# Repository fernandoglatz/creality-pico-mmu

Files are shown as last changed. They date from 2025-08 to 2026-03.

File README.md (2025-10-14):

# Creality Pico MMU

A firmware and tooling stack for a custom **8-line Multi-Material Unit (MMU)** for the **Creality Ender 3 V3 KE** 3D printer. The project provides:

* A **C++ firmware** for ATmega328P (Arduino Pro Mini/Nano) that controls the MMU hardware via serial communication.
* A **Python daemon** (`mmu_daemon.py`) that manages serial communication, provides automatic reconnection, and integrates with Klipper via socket interface.
* A **Python command-line interface** (`mmu_cmd.py`) to send commands to the MMU daemon.
* **Klipper configuration** (`pico-mmu.cfg`) with macros for seamless integration with Klipper firmware.
* Hardware designs for filament cutter and filament hub components.

## Features

✨ **8-Line Multi-Material System**
- Supports up to 8 different filament colors/materials simultaneously
- Individual filament presence sensors for each line
- Real-time filament state monitoring

🎯 **Automatic Filament Management**
- Servo-driven filament selector with precise positioning
- Automatic filament cutting between material changes
- Smart extrude/retract with acceleration control
- Stuck filament detection and error handling

🔌 **Seamless Klipper Integration**
- Native G-code macros (T0-T7 for tool changes)
- Daemon-based architecture with automatic reconnection
- HTTP API integration with Klipper
- State persistence across restarts

💡 **Visual & Audio Feedback**
- 16 RGB LEDs (WS2812B) showing filament status
- Color-coded status indicators per filament
- Musical notifications for events (startup, errors, success)
- Action button for manual control

🛠️ **Hardware Design Included**
- Custom filament cutter with dual 5015 fan cooling
- 9-line filament hub with integrated runout sensor
- Protoboard wiring diagram for easy assembly
- 3D printable STL files available on Printables

⚙️ **Highly Configurable**
- Adjustable servo positions, speeds, and distances
- Configurable acceleration curves
- Per-setup calibration via Klipper macros
- Runtime parameter synchronization

## System Requirements

### Hardware
- Creality Ender 3 V3 KE (or compatible 3D printer)
- ATmega328P microcontroller (Arduino Pro Mini 16MHz or Arduino Nano)
- MCP23017 I2C I/O expander
- 2x Servo motors (selector + cutter)
- Stepper motor with driver for filament feeding
- WS2812B NeoPixel LED strip (16 LEDs)
- 8x Filament sensors + 1x Hub sensor
- Piezo buzzer
- Push button
- Various electronics components (see Hardware section)

### Software
- Klipper firmware on printer
- Python 3.x
- PlatformIO (for firmware compilation)
- pyserial Python library

---

## Table of Contents

- [Creality Pico MMU](#creality-pico-mmu)
  - [Features](#features)
  - [System Requirements](#system-requirements)
  - [Table of Contents](#table-of-contents)
  - [Hardware](#hardware)
  - [Filament Cutter](#filament-cutter)
  - [Filament Hub](#filament-hub)
  - [Software Architecture](#software-architecture)
  - [Getting Started](#getting-started)
  - [Building the Firmware](#building-the-firmware)
  - [Running the Daemon](#running-the-daemon)
  - [Command Line Tool](#command-line-tool)
  - [Klipper Integration](#klipper-integration)
  - [Troubleshooting](#troubleshooting)
  - [Development](#development)
  - [Contributing](#contributing)
  - [License](#license)

---

## Hardware

The firmware targets an **ATmega328P** microcontroller (Arduino Pro Mini or Arduino Nano) that controls an 8-line MMU system with integrated sensors, servos, and LED feedback. 

### Core Components

- **Microcontroller**: ATmega328P (Arduino Pro Mini 16MHz or Arduino Nano)
- **I/O Expander**: MCP23017 (I2C) - provides 16 additional GPIO pins for sensors and control
- **LED System**: WS2812B NeoPixel strip (16 LEDs arranged as 2 bars of 8 LEDs each)
- **Servos**: 
  - MMU selector servo (positions filament selector wheel)
  - Filament cutter servo (operates cutting mechanism)
- **Stepper Motor**: Controls filament feeding/retracting with configurable acceleration/deceleration
- **Audio Feedback**: Piezo buzzer for status notifications
- **Sensors**:
  - 8x filament presence sensors (one per filament line)
  - 1x filament hub sensor (detects filament movement)
  - 1x action button (manual control)

### Pin Configuration

#### Direct ATmega328P Pins
| Pin | Function | Description |
|-----|---|---|
| D2 | Filament Hub Sensor | Interrupt-driven sensor for filament movement detection |
| D3 | Cutter Servo PWM | Controls filament cutting servo |
| D5 | NeoPixel Data | WS2812B LED strip data line |
| D6 | Buzzer | Piezo buzzer for audio feedback |
| D7 | MMU Direction | Stepper motor direction control |
| D8 | MMU Step | Stepper motor step signal |
| D9 | MMU Enable | Stepper motor enable/disable |
| D10 | MMU Servo PWM | Controls MMU selector servo |
| SDA/SCL | I2C Bus | Communication with MCP23017 |

#### MCP23017 I/O Expander Pins
| Pin | Function | Description |
|-----|---|---|
| 0 | Action Button | Manual control button (INPUT_PULLUP) |
| 1 | Creality Filament Sensor | Output signal to printer's filament runout sensor |
| 8-15 | Filament Sensors 1-8 | Individual filament presence detection (INPUT_PULLUP) |

### Hardware Features

- **Stepper Motor Control**: Microstepping (64 microsteps), configurable RPM (50-500), acceleration/deceleration curves
- **LED Status Indicators**: Per-filament status (idle, active, loaded, error states)
- **Audio Notifications**: Startup, error, filament inserted/removed, success melodies
- **Sensor Monitoring**: Real-time filament presence and movement detection
- **Servo Control**: Precise positioning for filament selection and cutting

The `pcb/` directory contains a protoboard diagram (`protoboard-diagram.fzz`) for wiring the components.

## Filament Cutter

The **Filament Cutter** is a custom toolhead modification designed specifically for use with the 8-line Pico MMU on the **Creality Ender 3 V3 KE**. This component enables automatic filament cutting between material changes, eliminating the need for manual intervention.

The design is based on the FatBurner cooling system and integrates a servo-driven blade mechanism that cuts the filament between the extruder motor and the hotend.

**Model files:** [Printables - Filament Cutter](https://www.printables.com/model/1433552-filament-cutter-creality-ender-3-v3-ke)

### Features

- Servo-driven cutting mechanism using TD-8120MG (20Kg) or MG995 (10Kg) servo
- Integrated dual 5015 fan cooling system (FatBurner-based)
- 4020 hotend fan adapter
- Compact design that fits between the extruder motor and hotend
- Uses standard box cutter blade for reliable cutting

### Required Parts

- **8x** Brass insert nut M3 (4mm OD x 4mm length)
- **4x** Superb screws (for the fan adapter)
- **4x** M3 flat head Allen screws (20mm)
- **2x** M3 flat head Allen screws (8mm)
- **1x** M3 flat head Allen screw (6mm)
- **4x** M3 Allen screws (8mm)
- **2x** M3 Allen screws (25mm)
- **2x** Fan 5015 (24V)
- **1x** Fan 4020 (24V)
- **3x** JST SH1 mini 1.25mm connector
- **6x** Heat shrink tubes
- **1x** Servo TD-8120MG (20Kg) or MG995 (10Kg)
- **1x** PTFE tube (1m, Creality 2mm ID)
- **1x** Box cutter blade

### Print Settings

- **Infill:** 100%
- **Support:** Yes
- **Support Type:** Snug and Tree Organic (for the FatBurner frame)
- **Raft Layers:** 10 (only for the FatBurner frame)

**Recommendations:**
- Print parts close to the hotend in **ABS** to avoid PLA deformation
- Use the **TD-8120MG 20Kg servo** for better robustness
- Verify your MMU board supports the servo current requirements
- Check camera mount clearance to avoid collisions

### Assembly Instructions

1. **Print all parts** using the provided 3MF file in `models/filament-cutter/`
2. **Insert brass insert nuts** into all designated holes
3. **Modify fan connectors:**
   - Replace 5015 and 4020 fan connectors with JST SH1 mini
   - May need to invert GND/24V pins in the connector
4. **Assemble cooling system:**
   - Attach 5015 fans to the FatBurner frame
   - Attach 40mm fan adapter to the hotend
   - Attach 4020 fan to the adapter
5. **Prepare hotend:**
   - Disassemble the toolhead (detach radiator from rear panel)
   - Cut PTFE tube, leaving only 1mm protruding from hotend radiator
   - Make an internal cone-shaped cut in the PTFE to facilitate filament entry
6. **Install cutting mechanism:**
   - Attach cutting base to hotend radiator using 25mm screws
   - Attach extruder motor
   - Insert box cutter blade into blade support using pliers (use cyanoacrylate glue to secure)
7. **Test cutting:**
   - Insert filament for testing
   - Manually push blade support into cutting base to verify cutting action
8. **Final assembly:**
   - Connect fans to extruder plate
   - Attach FatBurner frame with 6mm screw
   - Position servo holder with 8mm screws
   - Insert gear into servo (requires considerable force)
9. **Servo setup:**
   - Connect servo to power and set to initial position (0°)
   - Insert blade support, lightly touch filament, then back off 1mm
   - Insert servo into holder (mark blade support position for future maintenance)
   - Tighten all servo screws
   - Test cutting angle electronically (typically ~90°, always return to 0° between tests)
   - Apply petroleum jelly to moving parts

### Design Notes

This filament cutter is a remix that combines elements from several existing designs:

- Based on [FatBurner cooling system](https://www.printables.com/model/887597-fatburner-ender-3-v3-ke-dual-5015-fan-cooling-syst)
- Adapted cutting mechanism from [Ender 3 V3 SE filament cutter](https://www.printables.com/model/1277295-filament-cutter-for-ender-3-v3-se-servo-motor-edit)
- Uses [40mm fan adapter](https://www.printables.com/model/718283-ender-3-v3-se-25-40mm-fan-bracket-low-profile)

**Key modifications:**
- Custom cutout in FatBurner frame to accommodate filament cutter
- Shortened right-side duct for improved airflow
- Relocated mounting holes and reinforced structure on cutting base

## Filament Hub

The **Filament Hub** is a 9-line filament distribution system designed for the custom 8-line Pico MMU on the **Creality Ender 3 V3 KE**. It manages multiple filament feeds and includes an integrated filament runout sensor to detect when filament runs out during printing.

The hub uses ECAS04 push-to-connect fittings for quick and secure PTFE tube connections, and features a KW11-3Z micro switch for runout detection.

**Model files:** [Printables - Filament Hub 9 Lines](https://www.printables.com/model/1432682-filament-hub-9-lines-creality-ender-3-v3-ke)

### Features

- 9-line capacity (supports 8-line MMU plus one spare)
- Integrated filament runout sensor with micro switch
- ECAS04 quick-connect fittings for all filament lines
- Compact design suitable for mounting on printer frame
- Compatible with standard 1.75mm filament

### Required Parts

- **2x** M3 Allen screws (8mm)
- **2x** M3 Allen screws (10mm)
- **9x** ECAS04 connector (push-to-connect PTFE fittings)
- **1x** KW11-3Z micro switch (filament runout sensor)
- **1x** Zip tie (for cable management)

### Print Settings

- **Infill:** 100%
- **Support:** Yes
- **Support Type:** Tree Organic
- **Raft Layers:** 10

**Important Notes:**
- Do **NOT** add support on top of the hub - supports must only be on the bottom/sides
- Adding supports on top will make them impossible to remove and may damage the hub
- All models are oriented correctly for printing in the 3MF file

### Assembly and Maintenance

1. **Print the hub** using the provided 3MF file in `models/filament-hub/`
2. **Install ECAS04 connectors:**
   - Insert connectors into all 9 ports
   - Use cyanoacrylate glue to secure them permanently
3. **Install micro switch:**
   - Mount the KW11-3Z micro switch in the designated position
   - Secure with appropriate screws
4. **Mount the hub:**
   - Use M3 screws (8mm and 10mm) to mount hub to printer frame
   - Use zip tie for cable management
5. **Lubrication:**
   - Apply petroleum jelly to the inside of the hub
   - Apply petroleum jelly to the switch end cap
   - This ensures smooth filament movement and prevents binding
6. **Calibration:**
   - Test with different filament types
   - Adjust micro switch end-of-travel angle if needed for reliable detection
   - Fine-tune based on filament diameter variations

### Design Notes

This hub is a remix based on the [Filament Runout Sensor Enclosure](https://www.printables.com/model/11416-filament-runout-sensor-enclosure) by stevehlau, customized specifically for the Creality Ender 3 V3 KE and integrated with the 8-line Pico MMU system.

**Key features of the remix:**
- Expanded to 9 lines for full MMU support
- Optimized geometry for Ender 3 V3 KE mounting
- Integrated runout sensor in a compact form factor

## Software Architecture

The software stack consists of three main layers that work together to provide seamless multi-material printing:

### Repository Structure

| Directory | Purpose |
|---|---|
| `pico-mmu-controller/` | C++ firmware for ATmega328P. Built with PlatformIO. Handles low-level hardware control. |
| `script/` | Python daemon and utilities for system integration and communication. |
| `pcb/` | Hardware design files (Fritzing protoboard diagram). |
| `models/` | 3D printable components (filament cutter, filament hub). |

### Software Components

#### 1. Firmware (`main.cpp`)
The ATmega328P firmware provides:
- **Serial Protocol**: Command-based communication at 9600 baud
- **State Machine**: Manages filament states, sensor monitoring, and LED feedback
- **Motor Control**: Precise stepper control with acceleration/deceleration
- **Servo Control**: Position management for selector and cutter servos
- **Sensor Integration**: Real-time monitoring of 8 filament sensors and hub sensor
- **LED Feedback**: Visual status indication for each filament line
- **Audio Notifications**: Musical feedback for events (startup, errors, filament changes)

**Key Commands**:
- `START` - Initialize system
- `SYNC` - Synchronize configuration parameters
- `FILAMENT <n>` - Select filament line (0-7)
- `EXTRUDE <mm> <rpm>` - Feed filament
- `RETRACT <mm> <rpm>` - Retract filament
- `CUTTER_POSITION <angle>` - Control cutter servo
- `MMU_POSITION <angle>` - Control selector servo

#### 2. Daemon (`mmu_daemon.py`)
The Python daemon acts as a bridge between Klipper and the MMU firmware:
- **Serial Management**: Automatic port detection and reconnection
- **Socket Interface**: Unix socket server at `/tmp/pico_mmu_service.sock`
- **Command Queue**: Thread-safe command queuing and processing
- **State Persistence**: Saves current filament selection to `/var/lib/filament.txt`
- **Klipper Integration**: HTTP API calls to update Klipper state variables
- **Health Monitoring**: Tracks Arduino heartbeat (ALIVE messages every 5 seconds)
- **Auto-Recovery**: Restarts connection on communication failures

**Daemon Threads**:
- `scan_serial_ports`: Detects and connects to Arduino on USB/ACM ports
- `read_serial_background`: Continuous serial port monitoring
- `process_command_queue`: Sequential command execution
- `monitor_printer_status`: Watches Klipper state changes
- `monitor_arduino_status`: Detects communication timeouts
- `socket_server`: Handles client connections

#### 3. Command-Line Interface (`mmu_cmd.py`)
Simple utility to send commands directly to the daemon:
```bash
python3 mmu_cmd.py <command>
```
Communicates via Unix socket, waits for OK/ERROR response.

#### 4. Klipper Configuration (`pico-mmu.cfg`)
Provides G-code macros for integration:
- **Tool Selection**: `T0` through `T7` macros for filament selection
- **MMU Control**: Direct access to all MMU functions
- **Configuration Variables**: Adjustable parameters (positions, distances, speeds)
- **Automatic Filament Change**: `MMU_SWITCH_FILAMENT` macro handles complete swap sequence

**Configuration Parameters** (adjustable in `MMU_SWITCH_FILAMENT` macro):
- `filament_positions`: Servo angles for each filament (default: 170,148,126,104,80,56,32,10)
- `extrude_distance`: Filament feed distance in mm (default: 32)
- `retract_distance`: Filament retract distance in mm (default: 60)
- `mm_per_rotation`: Filament distance per motor rotation (default: 18.28571429)
- `mm_to_stuck`: Distance threshold for stuck detection (default: 80)
- `cutter_position_opened`: Cutter servo open angle (default: 0)
- `cutter_position_closed`: Cutter servo closed angle (default: 120)

## Getting Started

### Prerequisites

- **Hardware**: Assembled MMU system with ATmega328P, MCP23017, servos, stepper motor, sensors, and LEDs
- **3D Printer**: Creality Ender 3 V3 KE (or compatible) running Klipper firmware
- **Python**: Python 3.x installed on the printer's system
- **PlatformIO**: For compiling and flashing firmware

### Installation Steps

1. **Clone the repository**
   ```bash
   git clone https://github.com/fernandoglatz/creality-pico-mmu.git
   cd creality-pico-mmu
   ```

2. **Install PlatformIO** (if not already installed):
   ```bash
   pip install platformio
   ```

3. **Build and flash the firmware** (see [Building the Firmware](#building-the-firmware))

4. **Install Python dependencies** on your printer:
   ```bash
   pip install pyserial
   ```

5. **Copy scripts to printer**:
   ```bash
   # Copy to Klipper config directory
   cp script/mmu_daemon.py /usr/data/printer_data/config/pico-mmu/
   cp script/mmu_cmd.py /usr/data/printer_data/config/pico-mmu/
   cp script/pico-mmu.cfg /usr/data/printer_data/config/pico-mmu/
   ```

6. **Set up daemon service** (copy `script/S60mmu_daemon` to `/etc/init.d/` or create a systemd service)

7. **Include configuration in Klipper**:
   Add to your `printer.cfg`:
   ```ini
   [include pico-mmu/pico-mmu.cfg]
   ```

8. **Start the daemon**:
   ```bash
   /etc/init.d/S60mmu_daemon start
   ```
   Or manually:
   ```bash
   python3 /usr/data/printer_data/config/pico-mmu/mmu_daemon.py
   ```

## Building the Firmware

The firmware is located in `pico-mmu-controller/` and uses PlatformIO with the Arduino framework.

### Supported Boards

Two board configurations are available in `platformio.ini`:
- `pro16MHzatmega328` - Arduino Pro Mini 16MHz
- `nanoatmega328` - Arduino Nano (recommended)

### Build and Flash

```bash
cd pico-mmu-controller

# For Arduino Nano (recommended)
pio run -e nanoatmega328
pio run -e nanoatmega328 --target upload

# For Arduino Pro Mini
pio run -e pro16MHzatmega328
pio run -e pro16MHzatmega328 --target upload
```

### Dependencies

The firmware requires the following libraries (automatically installed by PlatformIO):
- `Servo` (v1.2.2) - Servo motor control
- `Adafruit NeoPixel` (v1.15.1) - WS2812B LED strip control
- `Adafruit MCP23017 Arduino Library` (v2.3.2) - I2C I/O expander

### Serial Monitor

After flashing, you can monitor the serial output:
```bash
pio device monitor -e nanoatmega328
```

The firmware will output:
```
Starting...
READY
```

Send `START` command to initialize the system.

## Running the Daemon

The daemon (`mmu_daemon.py`) manages communication between Klipper and the MMU firmware. It provides:
- Automatic serial port detection (`/dev/ttyUSB*`, `/dev/ttyACM*`)
- Auto-reconnection on communication failures
- Command queuing and processing
- Unix socket server for client communication
- State persistence and Klipper integration

### Manual Start

```bash
cd script
python3 mmu_daemon.py
```

The daemon logs to `/tmp/mmu_daemon.log` and console output.

### Service Installation

For automatic startup, use the provided init script:

```bash
# Copy the service script
sudo cp script/S60mmu_daemon /etc/init.d/
sudo chmod +x /etc/init.d/S60mmu_daemon

# Start the service
/etc/init.d/S60mmu_daemon start

# Enable on boot (depends on your system)
```

### Daemon Status

The daemon creates a Unix socket at `/tmp/pico_mmu_service.sock` for client connections.

Check if it's running:
```bash
ls -l /tmp/pico_mmu_service.sock
```

View logs:
```bash
tail -f /tmp/mmu_daemon.log
```

## Command Line Tool

The CLI (`mmu_cmd.py`) sends commands directly to the MMU daemon via Unix socket.

### Usage

```bash
python3 mmu_cmd.py <command>
```

### Available Commands

**System Commands:**
```bash
python3 mmu_cmd.py start              # Initialize MMU system
python3 mmu_cmd.py "sync FILAMENT_POSITIONS (...)"  # Sync configuration
```

**Filament Control:**
```bash
python3 mmu_cmd.py "filament 0"       # Select filament T0
python3 mmu_cmd.py filament_release   # Release filament selector
python3 mmu_cmd.py filament_reengage  # Re-engage last filament
```

**Motor Control:**
```bash
python3 mmu_cmd.py "extrude 32 500"   # Extrude 32mm at 500 RPM
python3 mmu_cmd.py "retract 60 210"   # Retract 60mm at 210 RPM
python3 mmu_cmd.py "mmu_rotate 360 500"  # Rotate motor 360° at 500 RPM
```

**Servo Control:**
```bash
python3 mmu_cmd.py "mmu_position 90"      # Set selector servo to 90°
python3 mmu_cmd.py "cutter_position 120"  # Set cutter servo to 120°
```

**Testing:**
```bash
python3 mmu_cmd.py test_leds          # Test all LEDs
python3 mmu_cmd.py "test_led 1"       # Test LED for filament 1
python3 mmu_cmd.py "midi 0"           # Play startup melody
```

### Exit Codes
- `0` - Command successful (received OK)
- `1` - Command failed (received ERROR or communication error)

## Klipper Integration

### Configuration

The `pico-mmu.cfg` file contains Klipper-compatible G-code macros and configuration. Key settings are in the `MMU_SWITCH_FILAMENT` macro:

```gcode
[gcode_macro MMU_SWITCH_FILAMENT]
variable_filament_positions: 170,148,126,104,80,56,32,10
variable_extrude_distance: 32
variable_retract_distance: 60
variable_mm_per_rotation: 18.28571429
variable_mm_to_stuck: 80
variable_cutter_position_opened: 0
variable_cutter_position_closed: 120
```

### Using in G-code

**Tool Selection:**
```gcode
T0  ; Select filament 0
T1  ; Select filament 1
T7  ; Select filament 7
```

**Manual Commands:**
```gcode
MMU_FILAMENT INDEX=3                    ; Select filament 3
MMU_EXTRUDE DISTANCE=50                 ; Extrude 50mm
MMU_RETRACT DISTANCE=60                 ; Retract 60mm
MMU_CUTTER_POSITION POSITION=120        ; Close cutter
MMU_FILAMENT_RELEASE                    ; Release selector
MMU_MIDI SLOT=4                         ; Play victory sound
```

### Filament Change Sequence

When you use `T0`-`T7`, the `MMU_SWITCH_FILAMENT` macro executes:
1. Syncs configuration with firmware
2. Heats extruder if needed (minimum 190°C)
3. Turns on cooling fan
4. Moves toolhead to safe position (X=-10)
5. Retracts current filament
6. Cuts filament
7. Retracts to MMU selector
8. Selects new filament
9. Feeds new filament to hotend
10. Purges filament (150mm on first change)
11. Verifies filament loaded correctly

## Troubleshooting

### Arduino Not Detected
- Check USB connection
- Verify the device appears: `ls -l /dev/ttyUSB* /dev/ttyACM*`
- Check daemon logs: `tail -f /tmp/mmu_daemon.log`
- Restart daemon: `/etc/init.d/S60mmu_daemon restart`

### Filament Not Loading
- Check sensor states in firmware output
- Verify filament is properly inserted in filament hub
- Check servo positions are calibrated correctly
- Verify stepper motor is powered and functioning

### Communication Timeout
- Daemon sends ALIVE heartbeat every 5 seconds
- If no response for 30 seconds, connection is reset
- Check serial baud rate matches (9600)
- Verify firmware is running: `pio device monitor`

### LED Status Meanings
- **Black**: No filament detected
- **Cyan**: Filament detected but not selected
- **White**: Currently selected/active
- **Green**: Filament loaded and ready
- **Dark Green**: Filament loaded, waiting at sensor
- **Orange**: Hub sensor stuck/not responding correctly
- **Red**: Error - filament missing or failed to load

### Configuration Issues
- Adjust `filament_positions` servo angles in `pico-mmu.cfg`
- Calibrate `mm_per_rotation` based on your extruder gear ratio
- Tune `extrude_distance` and `retract_distance` for your setup
- Set `cutter_position_opened` and `cutter_position_closed` for your servo

## Development

### Code Structure

**Firmware** (`pico-mmu-controller/src/main.cpp`):
- Setup functions for hardware initialization
- Serial command parser (`processSerialInput()`)
- Motor control with acceleration (`rotateMmu()`, `rotateMmuToSensor()`)
- Sensor monitoring (`readSensors()`, `readHubState()`)
- LED and audio feedback functions
- State management for filament selection

**Daemon** (`script/mmu_daemon.py`):
- Multi-threaded architecture for concurrent operations
- Serial port auto-detection and recovery
- Command queue processing
- Socket server for client communication
- Klipper HTTP API integration
- State persistence for filament selection

### Compile-Time Checks

The firmware includes compile-time assertions (`compile_checks.h`) to validate configuration:
- Array sizes match `NUMBER_OF_FILAMENTS`
- Configuration is consistent across all components

### Serial Communication Protocol

The firmware implements a text-based command protocol over serial (9600 baud):

**Command Format**: `COMMAND [ARGS]\n`

**Response Format**: `OK\n`, `ERROR\n`, or `ALIVE\n`

**Command Reference**:
| Command | Arguments | Description | Response |
|---|---|---|---|
| `START` | None | Initialize system, read sensors, display startup | `OK` |
| `SYNC` | `FILAMENT_POSITIONS (...) EXTRUDE_MM n RETRACT_MM n MM_PER_ROTATION f MM_TO_STUCK n CUTTER_OPENED n CUTTER_CLOSED n` | Synchronize configuration | `OK` |
| `FILAMENT` | `<0-7>` | Select filament line | `OK`/`ERROR` |
| `FILAMENT_RELEASE` | None | Release selector to neutral position | `OK` (async) |
| `EXTRUDE` | `<mm> [rpm]` | Feed filament (wait for hub sensor) | `OK` |
| `RETRACT` | `<mm> [rpm]` | Retract filament (wait for hub sensor) | `OK` (async) |
| `SWAP_FINISH` | None | Verify filament swap completed successfully | `OK`/`ERROR` |
| `MMU_POSITION` | `<angle>` | Set selector servo position | `OK` |
| `CUTTER_POSITION` | `<angle>` | Set cutter servo position | `OK` |
| `MMU_ROTATE` | `<degrees> [rpm]` | Rotate stepper motor | `OK` |
| `MIDI` | `<0-4>` | Play melody (0=startup, 1=error, 2=inserted, 3=removed, 4=victory) | `OK`/`ERROR` |
| `TEST_LEDS` | None | Test all LED strips | `OK` |
| `TEST_LED` | `<1-8>` | Test specific LED | `OK` |

**Logging Format**: `[<millis>] <LEVEL> - <message>`

**Example Session**:
```
[Arduino] --> START
[Arduino] <-- [123] INFO - Starting up...
[Arduino] <-- [456] INFO - Started
[Arduino] <-- OK
[Arduino] --> FILAMENT 0
[Arduino] <-- [789] INFO - Setting filament T0
[Arduino] <-- [1234] INFO - Filament set
[Arduino] <-- OK
```

### Debugging

Enable verbose logging:
```python
# In mmu_daemon.py
logger.setLevel(logging.DEBUG)
```

Monitor serial communication:
```bash
pio device monitor -e nanoatmega328 -b 9600
```

Test individual components:
```bash
python3 mmu_cmd.py test_leds
python3 mmu_cmd.py "test_led 1"
python3 mmu_cmd.py "midi 0"
```

Check daemon status:
```bash
# View real-time logs
tail -f /tmp/mmu_daemon.log

# Check socket exists
ls -l /tmp/pico_mmu_service.sock

# Test socket communication
echo "test_leds" | nc -U /tmp/pico_mmu_service.sock
```

## Contributing

Contributions are welcome! Please follow these guidelines:

1. **Open an issue** first to discuss major changes
2. **Fork the repository** and create a feature branch
3. **Follow the existing code style**:
   - C++ firmware: Arduino conventions
   - Python: PEP 8 style guide
4. **Test thoroughly**:
   - Verify firmware compiles without warnings
   - Test daemon with actual hardware
   - Ensure Klipper integration works correctly
5. **Document your changes**:
   - Update README if adding features
   - Add comments for complex logic
   - Update configuration examples if needed
6. **Submit a pull request** with clear description

### Areas for Improvement
- Add support for more than 8 filament lines
- Implement filament runout recovery
- Add web interface for configuration
- Support for different printer models
- Improved error recovery mechanisms

## License

This project is licensed under the Apache License 2.0 – see the [LICENSE](LICENSE) file for details.

### Third-Party Attributions

- **Filament Cutter**: Based on designs from:
  - [FatBurner cooling system](https://www.printables.com/model/887597-fatburner-ender-3-v3-ke-dual-5015-fan-cooling-syst)
  - [Ender 3 V3 SE filament cutter](https://www.printables.com/model/1277295-filament-cutter-for-ender-3-v3-se-servo-motor-edit)
  - [40mm fan adapter](https://www.printables.com/model/718283-ender-3-v3-se-25-40mm-fan-bracket-low-profile)

- **Filament Hub**: Remix based on:
  - [Filament Runout Sensor Enclosure](https://www.printables.com/model/11416-filament-runout-sensor-enclosure) by stevehlau

### Libraries Used

- Arduino Servo Library (v1.2.2) - LGPL 2.1
- Adafruit NeoPixel (v1.15.1) - LGPL 3.0
- Adafruit MCP23017 (v2.3.2) - BSD License
- Python pyserial - BSD License

---

Happy printing!

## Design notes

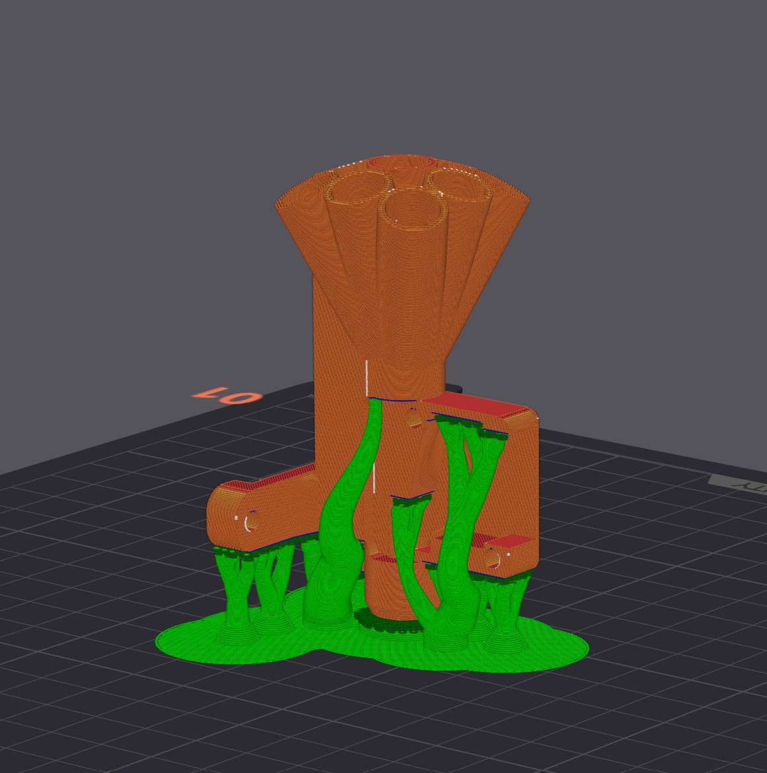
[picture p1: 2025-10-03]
models/filament-hub/filament-hub-slice-preview.jpg

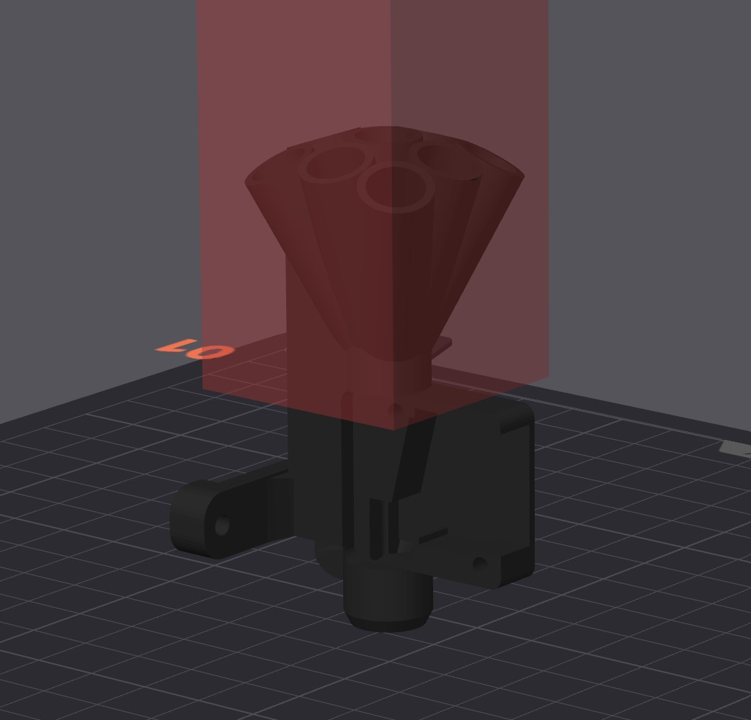
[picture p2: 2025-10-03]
models/filament-hub/filament-hub-block-support.jpg

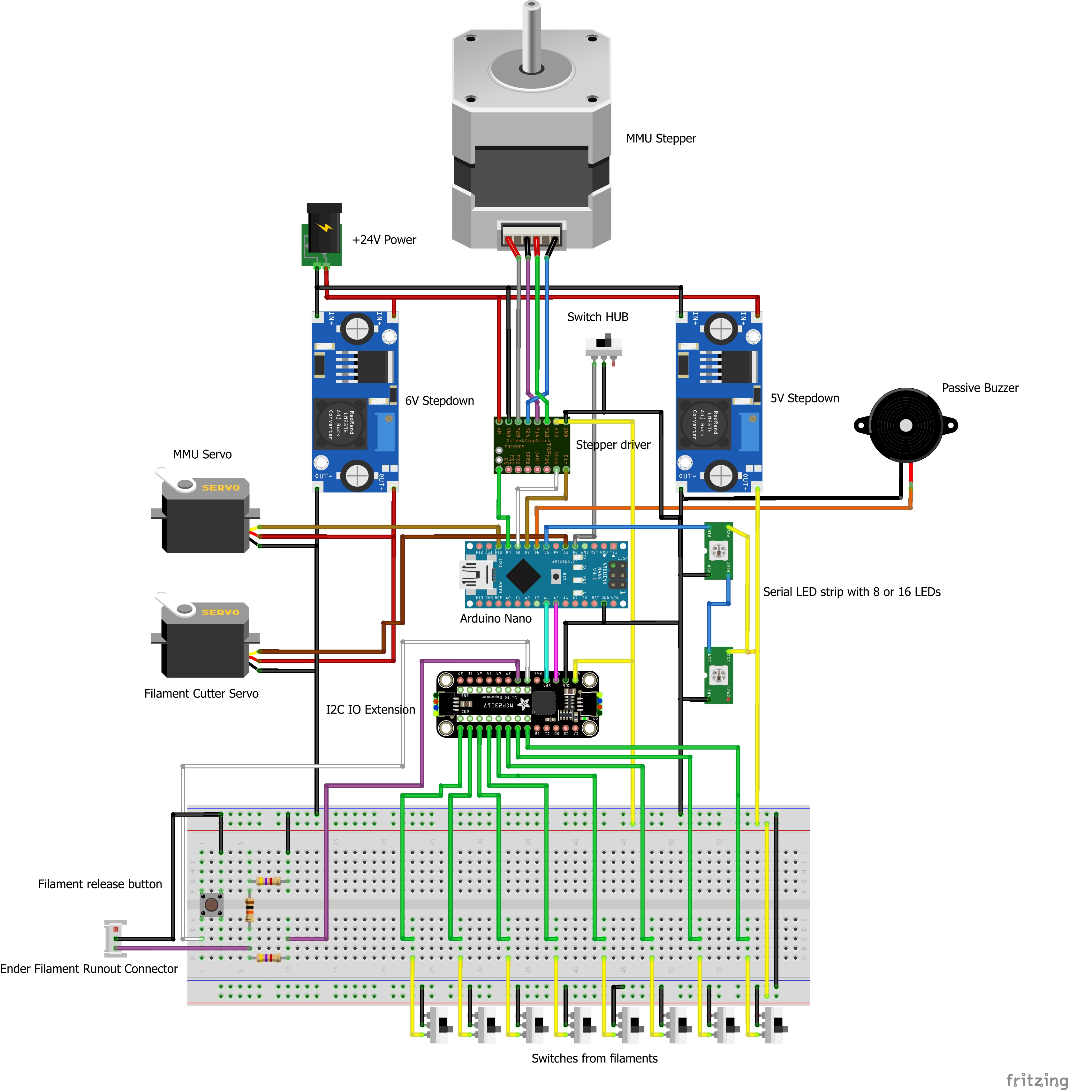
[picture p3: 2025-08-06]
pcb/protoboard-diagram.jpg

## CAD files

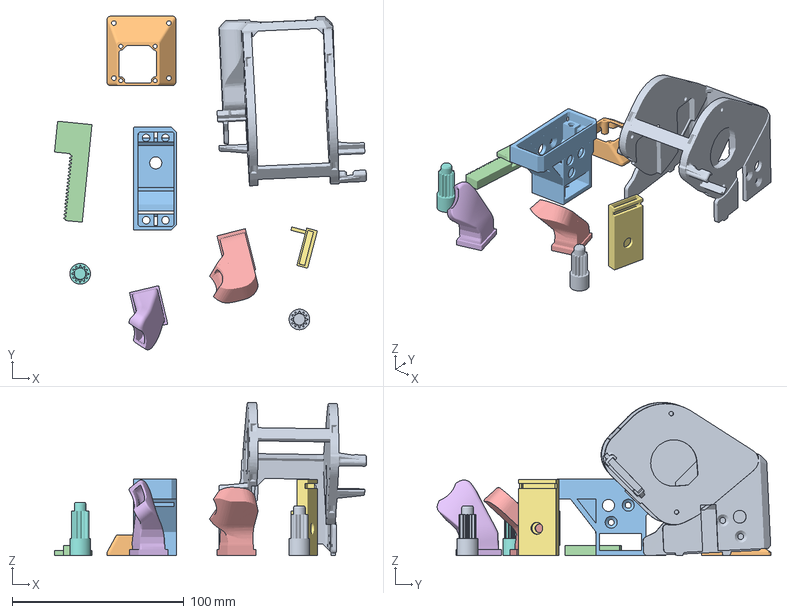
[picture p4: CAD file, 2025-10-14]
models/filament-cutter/filament-cutter.3mf
181.4 x 194.0 x 89.1 mm
fat-burner-frame.stl
fan-adapter-40mm.stl
servo-support.stl
blade-support.stl
fat-burner-duct-R.stl
fat-burner-duct-L.stl
cutter-base.stl
gear-for-MG995-10Kg.stl
gear-for-TD-8120MG-20Kg.stl

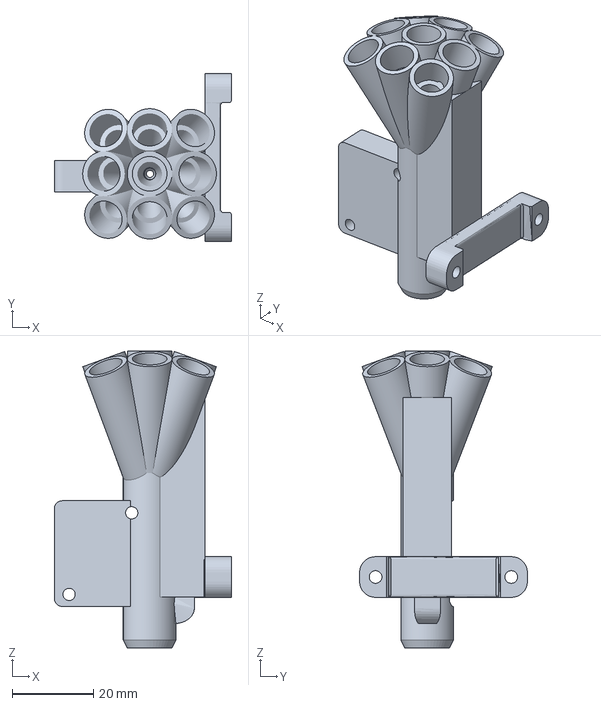
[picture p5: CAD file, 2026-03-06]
models/filament-hub/filament-hub.3mf
43.6 x 41.2 x 73.0 mm

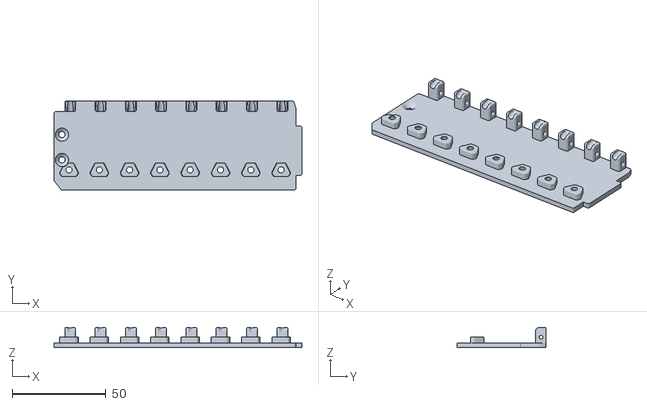
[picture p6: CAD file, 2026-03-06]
models/pico-mmu-8-lines/base.stl
132.4 x 47.8 x 10.7

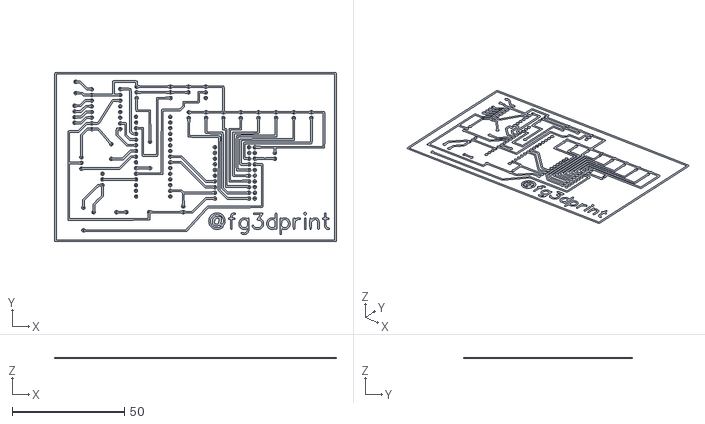
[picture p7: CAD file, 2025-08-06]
pcb/pcb.stl
125.8 x 75.6 x 0.3

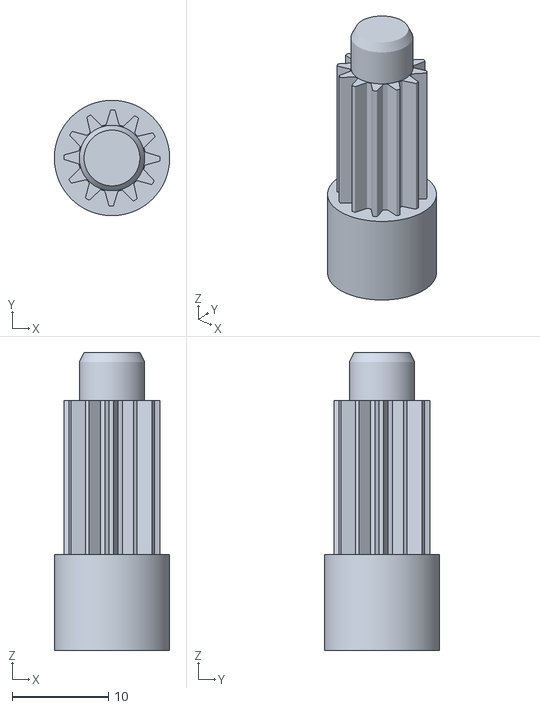
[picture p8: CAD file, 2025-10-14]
models/filament-cutter/gear-for-MG995-10Kg.stl
12.0 x 12.0 x 31.0

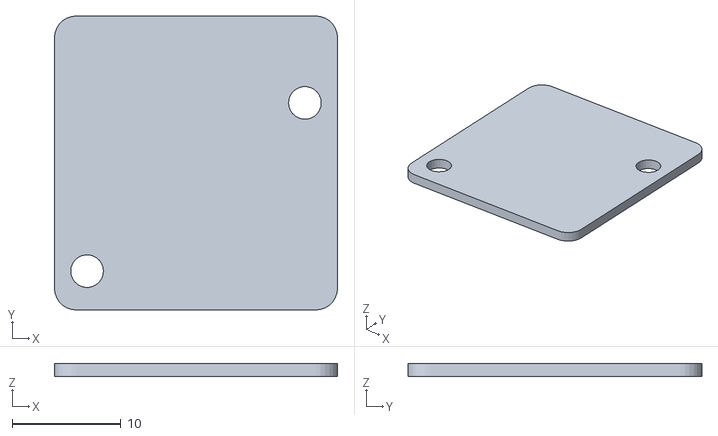
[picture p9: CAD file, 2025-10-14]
models/filament-hub/filament-hub-cover.stl
26.0 x 27.0 x 1.20

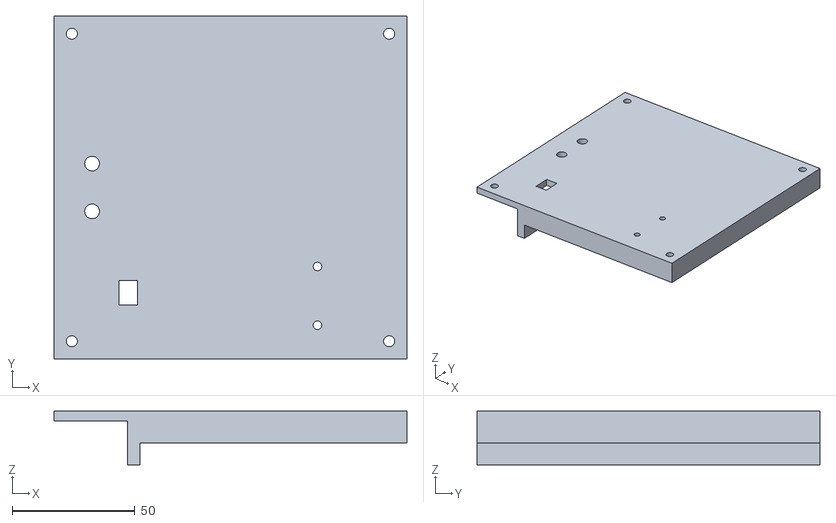
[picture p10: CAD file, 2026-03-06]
models/gantry-support/base.stl
144.0 x 140.0 x 22.0

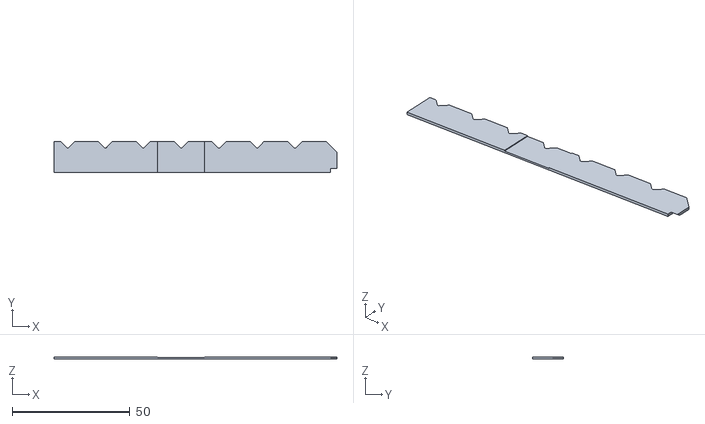
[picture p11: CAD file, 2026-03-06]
models/pico-mmu-8-lines/led-back-cover.stl
120.4 x 13.2 x 1.00

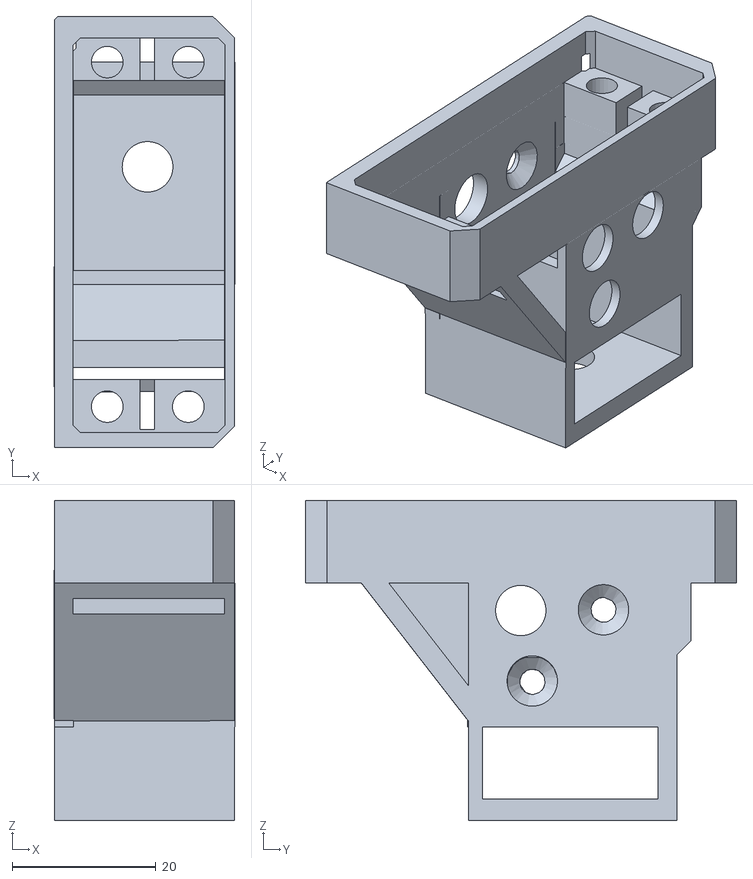
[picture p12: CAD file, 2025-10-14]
models/filament-cutter/servo-support.stl
25.1 x 59.9 x 44.5

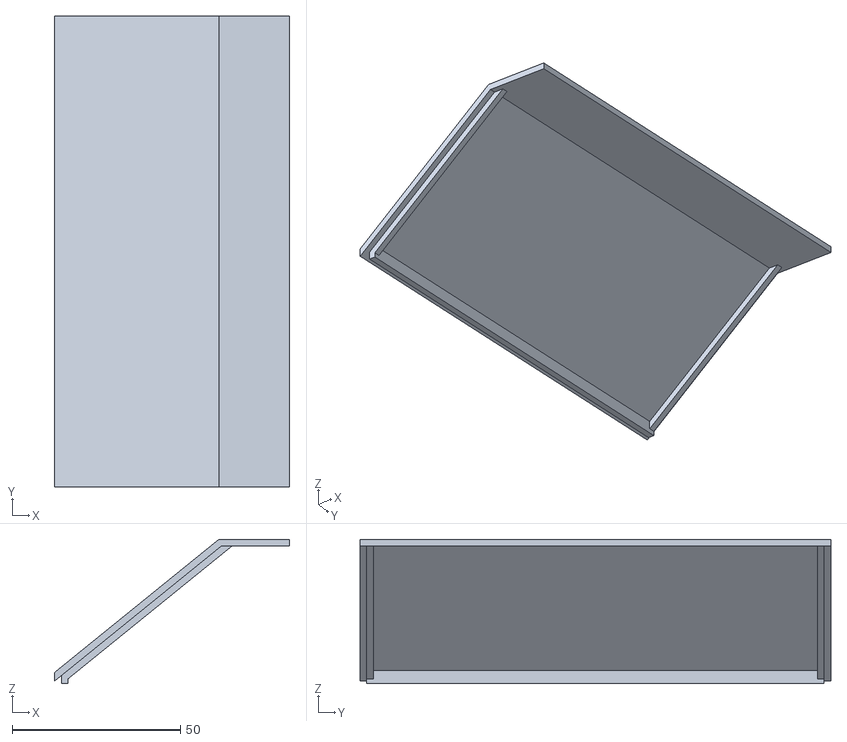
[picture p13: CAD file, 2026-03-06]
models/gantry-support/cover.stl
70.0 x 140.0 x 42.9

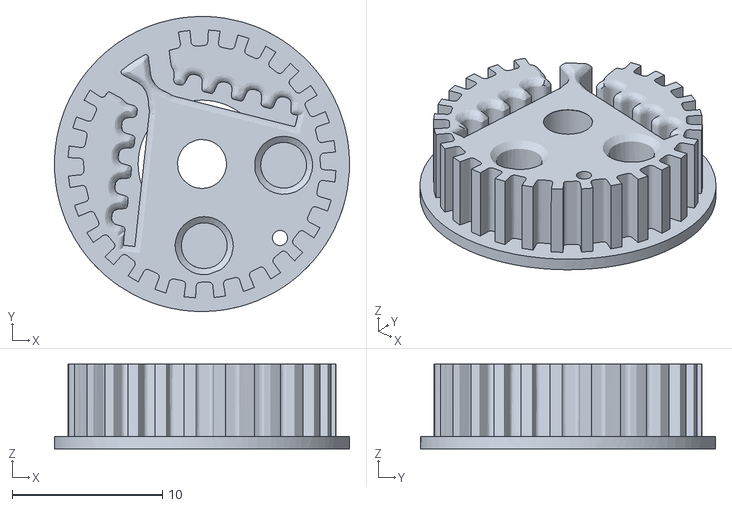
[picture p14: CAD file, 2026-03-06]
models/pico-mmu-8-lines/crankshaft-pulley.stl
19.7 x 19.7 x 5.66

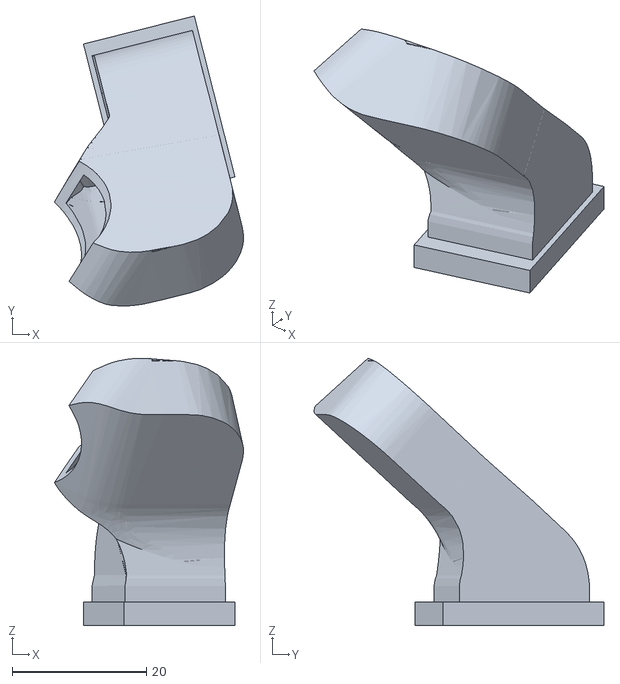
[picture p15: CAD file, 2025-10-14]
models/filament-cutter/fat-burner-duct-R.stl
28.2 x 43.2 x 39.8

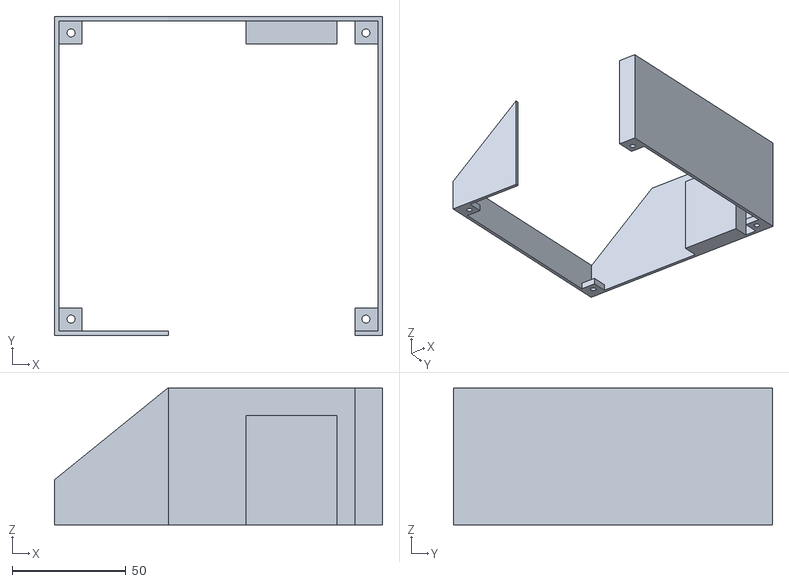
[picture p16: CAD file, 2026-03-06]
models/gantry-support/wall-support.stl
144.0 x 140.0 x 60.0

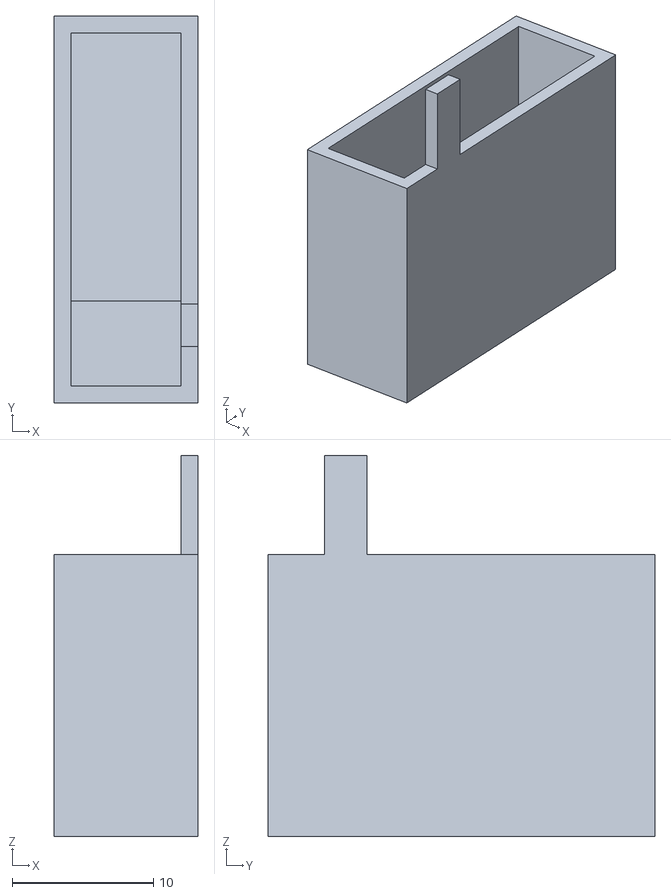
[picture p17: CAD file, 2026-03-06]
models/pico-mmu-8-lines/filament-sensor-cover.stl
10.2 x 27.4 x 27.0

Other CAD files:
models/filament-cutter/fat-burner-frame.stl
models/gantry-support/gantry-support.3mf
models/pico-mmu-8-lines/led-base.stl
models/filament-cutter/gear-for-TD-8120MG-20Kg.stl
models/filament-cutter/blade-support.stl
models/filament-cutter/cutter-base.stl
models/filament-cutter/fan-adapter-40mm.stl
models/filament-cutter/fat-burner-duct-L.stl
models/filament-hub/filament-hub.stl
models/gantry-support/screw-cap.stl
models/pico-mmu-8-lines/crankshaft.stl
models/pico-mmu-8-lines/filament-sensor.stl
models/pico-mmu-8-lines/led-transparent-window.stl
models/pico-mmu-8-lines/pico-mmu-8-lines.3mf
models/pico-mmu-8-lines/top-reinforcement.stl

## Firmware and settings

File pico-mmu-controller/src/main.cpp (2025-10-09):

#include <Adafruit_MCP23X17.h>
#include <Adafruit_NeoPixel.h>
#include <Arduino.h>
#include <Servo.h>

#define LED_PIN 5
#define BUZZER_PIN 6

#define MMU_DIR_PIN 7
#define MMU_STEP_PIN 8
#define MMU_ENABLE_PIN 9

#define MMU_SERVO_PIN 10
#define CUTTER_SERVO_PIN 3

#define BAUD_RATE 9600

#define MMU_SLOW_PULSE_DELAY 50
#define MMU_ACCEL_DECEL_SKIP_STEPS 200UL
#define MMU_MOTOR_STEPS 200
#define MMU_DEFAULT_RPM 500
#define MMU_MICROSTEPS 64
#define MMU_MIN_RPM 50
#define MMU_DIRECTION HIGH

#define NUM_LEDS 16  // 2 bars of 8 LEDs each
#define NUMBER_OF_FILAMENTS 8
#define FILAMENT_RELEASE_OFFSET 2

#define FILAMENT_HUB_SENSOR_PIN 2

#define ACTION_BUTTON_PIN 0
#define CREALITY_FILAMENT_SENSOR_PIN 1

#define FILAMENT_ONE_SENSOR_PIN 15
#define FILAMENT_TWO_SENSOR_PIN 14
#define FILAMENT_THREE_SENSOR_PIN 13
#define FILAMENT_FOUR_SENSOR_PIN 12
#define FILAMENT_FIVE_SENSOR_PIN 11
#define FILAMENT_SIX_SENSOR_PIN 10
#define FILAMENT_SEVEN_SENSOR_PIN 9
#define FILAMENT_EIGHT_SENSOR_PIN 8

#define ALIVE_MESSAGE_INTERVAL 5000

#define NOTE_A4 440
#define NOTE_A5 880
#define NOTE_B5 988
#define NOTE_C5 523
#define NOTE_C6 1047
#define NOTE_D5 587
#define NOTE_E5 659
#define NOTE_F5 698
#define NOTE_G5 784
#define NOTE_C4 262
#define NOTE_E4 330
#define NOTE_G4 392

const int STARTUP_MELODY[] = {NOTE_C4, NOTE_E4, NOTE_G4, NOTE_C5};
const int STARTUP_NOTE_DURATIONS[] = {200, 200, 200, 500};

const int ERROR_MELODY[] = {NOTE_A4, NOTE_A4, NOTE_A4};
const int ERROR_NOTE_DURATIONS[] = {200, 200, 600};

const int FILAMENT_INSERTED_MELODY[] = {NOTE_C5, NOTE_E5, NOTE_G5};
const int FILAMENT_INSERTED_NOTE_DURATIONS[] = {150, 150, 300};

const int FILAMENT_REMOVED_MELODY[] = {NOTE_G5, NOTE_E5, NOTE_C5};
const int FILAMENT_REMOVED_NOTE_DURATIONS[] = {150, 150, 300};

const int MARIO_VICTORY_MELODY[] = {
    NOTE_E5, NOTE_G5, NOTE_C6, NOTE_B5,
    NOTE_A5, NOTE_F5, NOTE_D5, NOTE_E5};

const int MARIO_VICTORY_NOTE_DURATIONS[] = {
    150, 150, 300, 300,
    300, 300, 300, 600};

const int FILAMENT_LEDS[] = {0, 3, 5, 7, 8, 11, 13, 15};
const int FILAMENT_SENSOR_PINS[] = {FILAMENT_ONE_SENSOR_PIN, FILAMENT_TWO_SENSOR_PIN, FILAMENT_THREE_SENSOR_PIN,
                                    FILAMENT_FOUR_SENSOR_PIN, FILAMENT_FIVE_SENSOR_PIN, FILAMENT_SIX_SENSOR_PIN,
                                    FILAMENT_SEVEN_SENSOR_PIN, FILAMENT_EIGHT_SENSOR_PIN};

long ledStates[] = {0, 0, 0, 0, 0, 0, 0, 0, 0, 0, 0, 0, 0, 0, 0, 0};
bool filamentStates[] = {HIGH, HIGH, HIGH, HIGH, HIGH, HIGH, HIGH, HIGH};

Adafruit_NeoPixel pixels(NUM_LEDS, LED_PIN);
Adafruit_MCP23X17 mcp;
Servo mmuServo;
Servo cutterServo;

int lastColorIndex = -1;
int lastFilamentLED = -1;
int lastMMUPosition = 0;
int activeFilament = -1;

unsigned long previousAliveMessageMillis = 0;
unsigned long previousStartupBlinkMillis = 0;
bool startupBlinkState = false;

bool started = false;
bool hubState = HIGH;
bool lastHubState = HIGH;
bool hubStateStucked = false;
bool autoExtruding = false;

const long BLACK_COLOR = pixels.Color(0, 0, 0);
const long RED_COLOR = pixels.Color(255, 0, 0);
const long GREEN_COLOR = pixels.Color(0, 255, 0);
const long DARK_GREEN_COLOR = pixels.Color(0, 25, 0);
const long BLUE_COLOR = pixels.Color(0, 0, 255);
const long YELLOW_COLOR = pixels.Color(255, 255, 0);
const long WHITE_COLOR = pixels.Color(255, 255, 255);
const long CYAN_COLOR = pixels.Color(0, 150, 255);
const long MAGENTA_COLOR = pixels.Color(255, 0, 255);
const long ORANGE_COLOR = pixels.Color(255, 128, 0);

// button control
const unsigned long PRESS_INTERVAL = 500;

// config from machine
// default, change it in printer config
int filamentPositions[] = {170, 148, 126, 104, 80, 56, 32, 10};
long extrudeMillimeters = 32;
long retractMillimeters = 60;
long millimetersToStuck = 80;
double millimetersPerRotation = 18.28571429;
int cutterServoPositionOpened = 0;
int cutterServoPositionClosed = 120;

void logInfo(const String& message, const String& extra) {
    Serial.print("[");
    Serial.print(millis());
    Serial.print("] INFO - ");
    Serial.print(message);
    Serial.println(extra);
}

void logWarn(const String& message, const String& extra) {
    Serial.print("[");
    Serial.print(millis());
    Serial.print("] WARN - ");
    Serial.print(message);
    Serial.println(extra);
}

void logError(const String& message, const String& extra) {
    Serial.print("[");
    Serial.print(millis());
    Serial.print("] ERROR - ");
    Serial.print(message);
    Serial.println(extra);
}

void responseOk() {
    Serial.println("OK");
}

void responseError() {
    Serial.println("ERROR");
}

void responseAlive() {
    Serial.println("ALIVE");
}

void changeLED(int index, long color) {
    int position = FILAMENT_LEDS[index];

    pixels.setPixelColor(position, color);
    pixels.show();
}

void blinkLED(int index, long color) {
    for (int i = 0; i < 5; i++) {
        changeLED(index, color);
        delay(200);

        changeLED(index, BLACK_COLOR);
        delay(200);
    }

    changeLED(index, color);
}

void disableLEDs() {
    for (int i = 0; i < NUM_LEDS; i++) {
        pixels.setPixelColor(i, BLACK_COLOR);
    }
    pixels.show();
}

void startupLEDs() {
    for (int i = 0; i < NUMBER_OF_FILAMENTS; i++) {
        changeLED(i, CYAN_COLOR);
        delay(100);
    }
}

void finishStartupLEDs() {
    for (int i = NUMBER_OF_FILAMENTS - 1; i >= 0; i--) {
        changeLED(i, BLACK_COLOR);
        delay(100);
    }
}

void blinkStartupLEDs() {
    unsigned long currentMillis = millis();
    if (currentMillis - previousStartupBlinkMillis >= 500) {
        previousStartupBlinkMillis = currentMillis;
        startupBlinkState = !startupBlinkState;

        for (int i = 0; i < NUMBER_OF_FILAMENTS; i++) {
            changeLED(i, BLACK_COLOR);
            if (startupBlinkState) {
                changeLED(i, ORANGE_COLOR);
            } else {
                changeLED(i, BLACK_COLOR);
            }
        }
    }
}

void blinkErrorLEDs() {
    while (true) {
        for (int i = 0; i < NUMBER_OF_FILAMENTS; i++) {
            changeLED(i, RED_COLOR);
        }
        delay(500);

        for (int i = 0; i < NUMBER_OF_FILAMENTS; i++) {
            changeLED(i, BLACK_COLOR);
        }
        delay(500);
    }
}

void saveLEDStates() {
    for (int i = 0; i < NUM_LEDS; i++) {
        ledStates[i] = pixels.getPixelColor(i);
    }
}

void restoreLEDStates() {
    for (int i = 0; i < NUM_LEDS; i++) {
        pixels.setPixelColor(i, ledStates[i]);
    }
    pixels.show();
}

void changeMusicLED(int index) {
    long color;
    int currentColorIndex;

    do {
        currentColorIndex = random(0, 7);
    } while (currentColorIndex == lastColorIndex);

    lastColorIndex = currentColorIndex;

    switch (currentColorIndex) {
        case 0:
            color = RED_COLOR;
            break;
        case 1:
            color = GREEN_COLOR;
            break;
        case 2:
            color = BLUE_COLOR;
            break;
        case 3:
            color = YELLOW_COLOR;
            break;
        case 4:
            color = WHITE_COLOR;
            break;
        case 5:
            color = CYAN_COLOR;
            break;
        case 6:
            color = MAGENTA_COLOR;
            break;
        case 7:
            color = ORANGE_COLOR;
            break;
    }

    changeLED(index, color);
}

void buttonClickSound() {
    int clickDuration = 50;

    tone(BUZZER_PIN, NOTE_C6, clickDuration);
    delay(clickDuration * 1.3);
    noTone(BUZZER_PIN);
}

void playMIDI(const int* melody, const int* noteDurations, int notes, bool ledEnabled) {
    if (ledEnabled) {
        saveLEDStates();
        disableLEDs();
    }

    for (int thisNote = 0; thisNote < notes; thisNote++) {
        int noteDuration = noteDurations[thisNote];
        int note = melody[thisNote];

        int filamentLED;

        do {
            filamentLED = random(0, NUMBER_OF_FILAMENTS - 1);
        } while (filamentLED == lastFilamentLED);

        lastFilamentLED = filamentLED;

        if (note == 0) {
            noTone(BUZZER_PIN);

        } else {
            tone(BUZZER_PIN, note, noteDuration);

            if (ledEnabled) {
                changeMusicLED(filamentLED);
            }
        }

        delay(noteDuration * 1.3);

        if (ledEnabled) {
            changeLED(filamentLED, BLACK_COLOR);
        }
    }

    noTone(BUZZER_PIN);

    if (ledEnabled) {
        restoreLEDStates();
    }
}

void startupMIDI(bool ledEnabled) {
    int notes = sizeof(STARTUP_MELODY) / sizeof(STARTUP_MELODY[0]);
    playMIDI(STARTUP_MELODY, STARTUP_NOTE_DURATIONS, notes, ledEnabled);
}

void errorMIDI(bool ledEnabled) {
    int notes = sizeof(ERROR_MELODY) / sizeof(ERROR_MELODY[0]);
    playMIDI(ERROR_MELODY, ERROR_NOTE_DURATIONS, notes, ledEnabled);
}

void filamentInsertedMIDI(bool ledEnabled) {
    int notes = sizeof(FILAMENT_INSERTED_MELODY) / sizeof(FILAMENT_INSERTED_MELODY[0]);
    playMIDI(FILAMENT_INSERTED_MELODY, FILAMENT_INSERTED_NOTE_DURATIONS, notes, ledEnabled);
}

void filamentRemovedMIDI(bool ledEnabled) {
    int notes = sizeof(FILAMENT_REMOVED_MELODY) / sizeof(FILAMENT_REMOVED_MELODY[0]);
    playMIDI(FILAMENT_REMOVED_MELODY, FILAMENT_REMOVED_NOTE_DURATIONS, notes, ledEnabled);
}

void marioVictoryMIDI(bool ledEnabled) {
    int notes = sizeof(MARIO_VICTORY_MELODY) / sizeof(MARIO_VICTORY_MELODY[0]);
    playMIDI(MARIO_VICTORY_MELODY, MARIO_VICTORY_NOTE_DURATIONS, notes, ledEnabled);
}

bool playMIDI(int position) {
    switch (position) {
        case 0:
            startupMIDI(true);
            return true;

        case 1:
            errorMIDI(true);
            return true;

        case 2:
            filamentInsertedMIDI(true);
            return true;

        case 3:
            filamentRemovedMIDI(true);
            return true;

        case 4:
            marioVictoryMIDI(true);
            return true;

        default:
            logError(F("Unknown MIDI "), String(position));
    }

    return false;
}

void setMissingFilament() {
    logInfo(F("Setting missing filament, pausing print"), "");
    mcp.digitalWrite(CREALITY_FILAMENT_SENSOR_PIN, HIGH);
}

void unsetMissingFilament() {
    mcp.digitalWrite(CREALITY_FILAMENT_SENSOR_PIN, LOW);
}

void changeHubState() {
    // Read raw pin state directly
    hubState = (PIND & (1 << FILAMENT_HUB_SENSOR_PIN));
    hubStateStucked = false;
}

long getDegreesFromMilimeters(long milimeters) {
    return milimeters * 360 / millimetersPerRotation;
}

long getStepsFromDegrees(long degrees) {
    return degrees * (unsigned long)MMU_MICROSTEPS * (unsigned long)MMU_MOTOR_STEPS / 360UL;
}

long getStepsFromMilimeters(long milimeters) {
    long degrees = getDegreesFromMilimeters(milimeters);
    return getStepsFromDegrees(degrees);
}

long getMilimetersFromSteps(unsigned long steps) {
    long degrees = steps * 360UL / (MMU_MICROSTEPS * MMU_MOTOR_STEPS);
    return degrees * millimetersPerRotation / 360;
}

void setCutterServoPosition(int position) {
    cutterServo.attach(CUTTER_SERVO_PIN);
    cutterServo.write(position);
    delay(1000);
    cutterServo.detach();
}

void setMMUServoPosition(int position) {
    lastMMUPosition = position;

    mmuServo.attach(MMU_SERVO_PIN);
    mmuServo.write(position);
    delay(1000);
    mmuServo.detach();
}

void testLED(int index) {
    logInfo(F("Testing LED "), String(index + 1));

    blinkLED(index, RED_COLOR);
    blinkLED(index, GREEN_COLOR);
    blinkLED(index, BLUE_COLOR);
    blinkLED(index, YELLOW_COLOR);
    blinkLED(index, CYAN_COLOR);
    blinkLED(index, MAGENTA_COLOR);
    blinkLED(index, ORANGE_COLOR);
    blinkLED(index, WHITE_COLOR);
}

void safeTestLED(int index) {
    logInfo(F("Testing LEDs"), "");

    saveLEDStates();
    testLED(index);
    restoreLEDStates();
}

void testLEDs() {
    logInfo(F("Testing LEDs"), "");

    saveLEDStates();

    for (int i = 0; i < NUMBER_OF_FILAMENTS; i++) {
        testLED(i);
    }

    restoreLEDStates();
}

bool setFilament(int index) {
    activeFilament = index;

    for (int i = 0; i < NUMBER_OF_FILAMENTS; i++) {
        bool filamentState = filamentStates[i];

        if (filamentState == LOW) {
            changeLED(i, CYAN_COLOR);
        } else {
            changeLED(i, BLACK_COLOR);
        }
    }

    changeLED(activeFilament, WHITE_COLOR);

    bool filamentState = filamentStates[activeFilament];
    int position = filamentPositions[activeFilament];

    setMMUServoPosition(position);

    if (filamentState == LOW) {
        unsetMissingFilament();

        if (hubStateStucked) {
            changeLED(activeFilament, ORANGE_COLOR);
        } else if (hubState == HIGH) {
            changeLED(activeFilament, DARK_GREEN_COLOR);
        } else {
            changeLED(activeFilament, GREEN_COLOR);
        }

    } else {
        changeLED(activeFilament, RED_COLOR);
        errorMIDI(false);
        blinkLED(activeFilament, RED_COLOR);
        return false;
    }

    return true;
}

void filamentRelease() {
    saveLEDStates();

    if (lastMMUPosition > 90) {
        changeLED(7, WHITE_COLOR);
        setMMUServoPosition(filamentPositions[7]);

    } else {
        changeLED(0, WHITE_COLOR);
        setMMUServoPosition(filamentPositions[0]);
    }

    restoreLEDStates();
}

bool swapFinish() {
    if (hubStateStucked || filamentStates[activeFilament] == HIGH) {
        setMissingFilament();
        errorMIDI(false);
        return false;
    }

    return true;
}

unsigned long rotateMmu(long degrees, int rpm, bool accelerationEnabled, bool decelerationEnabled, bool resetOnSensor) {
    if (degrees == 0) {
        return 0;
    }

    digitalWrite(MMU_ENABLE_PIN, LOW);

    if (degrees < 0) {
        digitalWrite(MMU_DIR_PIN, !MMU_DIRECTION);
        degrees *= -1;
    } else {
        digitalWrite(MMU_DIR_PIN, MMU_DIRECTION);
    }

    if (rpm == 0) {
        rpm = MMU_DEFAULT_RPM;
    } else if (rpm < MMU_MIN_RPM) {
        rpm = MMU_MIN_RPM;
    }

    unsigned long totalSteps = 0;
    unsigned long steps = getStepsFromDegrees(degrees);
    unsigned long decelerationSteps = steps - (steps / 100UL);

    unsigned long targetPulsePeriod = 60000000UL / ((unsigned long)rpm * (unsigned long)MMU_MICROSTEPS * (unsigned long)MMU_MOTOR_STEPS);
    unsigned int targetDelay = targetPulsePeriod / 2UL;
    unsigned int currentDelay = MMU_SLOW_PULSE_DELAY;
    unsigned long skipStepCount = 0;
    bool acelerated = false;
    bool lastHubState = hubState;

    if (!accelerationEnabled) {
        currentDelay = targetDelay;
    }

    for (unsigned long i = 0; i < steps; i++) {
        if (skipStepCount > MMU_ACCEL_DECEL_SKIP_STEPS) {
            if (decelerationEnabled && currentDelay != MMU_SLOW_PULSE_DELAY && i > decelerationSteps) {
                skipStepCount = 0;
                currentDelay += 1;

                if (currentDelay > MMU_SLOW_PULSE_DELAY) {
                    currentDelay = MMU_SLOW_PULSE_DELAY;
                }

            } else if (accelerationEnabled && !acelerated && currentDelay != targetDelay) {
                skipStepCount = 0;
                currentDelay -= 1;

                if (currentDelay < targetDelay) {
                    currentDelay = targetDelay;
                    acelerated = true;
                }
            }
        }

        skipStepCount++;
        totalSteps++;

        if (hubState != lastHubState && resetOnSensor) {
            logInfo(F("Resetting on filament sensor"), "");

            i = 0;
            skipStepCount = 0;
            currentDelay = targetDelay;
            lastHubState = hubState;
        }

        digitalWrite(MMU_STEP_PIN, HIGH);
        delayMicroseconds(currentDelay);
        digitalWrite(MMU_STEP_PIN, LOW);
        delayMicroseconds(currentDelay);
    }

    digitalWrite(MMU_ENABLE_PIN, HIGH);

    return totalSteps;
}

void rotateMmuToSensor(int targetState, long milimeters, long milimetersToStuck, int direction, int rpm) {
    if (milimeters == 0) {
        return;
    }

    if (hubState == targetState) {
        hubStateStucked = true;
        changeLED(activeFilament, ORANGE_COLOR);
        logWarn("Hub sensor stucked", (""));
    }

    digitalWrite(MMU_ENABLE_PIN, LOW);
    digitalWrite(MMU_DIR_PIN, direction);

    if (rpm == 0) {
        rpm = MMU_DEFAULT_RPM;
    } else if (rpm < MMU_MIN_RPM) {
        rpm = MMU_MIN_RPM;
    }

    unsigned long stepsToStuck = getStepsFromMilimeters(milimetersToStuck);

    if (direction != MMU_DIRECTION) {
        milimeters *= -1;  // retract
    }

    unsigned long targetPulsePeriod = 60000000UL / ((unsigned long)rpm * (unsigned long)MMU_MICROSTEPS * (unsigned long)MMU_MOTOR_STEPS);
    unsigned int targetDelay = targetPulsePeriod / 2UL;
    unsigned int currentDelay = MMU_SLOW_PULSE_DELAY;
    unsigned long skipStepCount = 0;
    unsigned long checkIntervalCount = 0;
    unsigned long steps = 0;

    while (hubState != targetState || hubStateStucked) {
        if (skipStepCount > MMU_ACCEL_DECEL_SKIP_STEPS && currentDelay != targetDelay) {
            skipStepCount = 0;
            currentDelay -= 1;

            if (currentDelay < targetDelay) {
                currentDelay = targetDelay;
            }
        }

        if (direction != MMU_DIRECTION && steps > stepsToStuck) {
            hubStateStucked = true;

            changeLED(activeFilament, ORANGE_COLOR);

            logWarn("Hub sensor stucked on retract", (""));
            break;

        } else if (direction == MMU_DIRECTION && steps > stepsToStuck && !autoExtruding) {
            hubStateStucked = true;

            changeLED(activeFilament, ORANGE_COLOR);

            logWarn("Hub sensor stucked on extrude", (""));
            break;
        }

        digitalWrite(MMU_STEP_PIN, HIGH);
        delayMicroseconds(currentDelay);
        digitalWrite(MMU_STEP_PIN, LOW);
        delayMicroseconds(currentDelay);

        checkIntervalCount++;
        skipStepCount++;
        steps++;
    }

    if (hubStateStucked) {
        changeLED(activeFilament, ORANGE_COLOR);
    } else if (hubState == HIGH) {
        changeLED(activeFilament, DARK_GREEN_COLOR);
    } else {
        changeLED(activeFilament, GREEN_COLOR);
    }

    long degrees = getDegreesFromMilimeters(milimeters);
    bool resetOnSensor = direction != MMU_DIRECTION;  // reset on retract
    unsigned long extraSteps = rotateMmu(degrees, rpm, false, true, resetOnSensor);
    steps = steps + extraSteps;

    long stepsMilimeters = getMilimetersFromSteps(steps);

    if (direction == MMU_DIRECTION) {
        logInfo(F("Extruded milimeters: "), String(stepsMilimeters));

    } else if (direction != MMU_DIRECTION) {
        logInfo(F("Retracted milimeters: "), String(stepsMilimeters));
    }

    digitalWrite(MMU_ENABLE_PIN, HIGH);
}

void extrude(long milimeters, int rpm) {
    long totalMilimetersToStuck = millimetersToStuck + retractMillimeters;
    rotateMmuToSensor(LOW, milimeters, totalMilimetersToStuck, MMU_DIRECTION, rpm);
}

void retract(long milimeters, int rpm) {
    long totalMilimetersToStuck = millimetersToStuck + extrudeMillimeters;
    rotateMmuToSensor(HIGH, milimeters, totalMilimetersToStuck, !MMU_DIRECTION, rpm);
}

void readHubState() {
    if (hubState != lastHubState) {
        logInfo(F("Hub state changed to "), String(hubState));
        lastHubState = hubState;

        if (activeFilament > -1 && filamentStates[activeFilament] == LOW && !hubStateStucked) {
            if (hubState == HIGH) {
                changeLED(activeFilament, DARK_GREEN_COLOR);
            } else {
                changeLED(activeFilament, GREEN_COLOR);
                unsetMissingFilament();
            }
        }
    }
}

void readSensors(bool soundEnabled) {
    for (int i = 0; i < NUMBER_OF_FILAMENTS; i++) {
        int pin = FILAMENT_SENSOR_PINS[i];
        bool state = mcp.digitalRead(pin);
        if (state != filamentStates[i]) {
            filamentStates[i] = state;

            if (state == LOW) {
                logInfo("Filament T" + String(i) + " inserted", "");

                if (i == activeFilament) {
                    unsetMissingFilament();

                    if (hubStateStucked) {
                        changeLED(activeFilament, ORANGE_COLOR);
                    } else {
                        changeLED(activeFilament, GREEN_COLOR);
                    }

                } else {
                    changeLED(i, CYAN_COLOR);
                }

                if (soundEnabled) {
                    filamentInsertedMIDI(false);
                }

            } else {
                logInfo("Filament T" + String(i) + " removed", "");

                if (i == activeFilament) {
                    setMissingFilament();

                    changeLED(i, RED_COLOR);

                    if (soundEnabled) {
                        errorMIDI(false);
                    }

                    blinkLED(i, RED_COLOR);

                } else {
                    changeLED(i, BLACK_COLOR);

                    if (soundEnabled) {
                        filamentRemovedMIDI(false);
                    }
                }
            }
        }
    }
}
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
void loop() {
    if (Serial.available() > 0) {
        processSerialInput();
    }

    if (started) {
        readSensors(true);
        readHubState();
        readActionButtonPressed();

        unsigned long currentMillis = millis();
        if (currentMillis - previousAliveMessageMillis > ALIVE_MESSAGE_INTERVAL) {
            responseAlive();
            previousAliveMessageMillis = currentMillis;
        }
    } else {
        blinkStartupLEDs();
    }
}

#include "compile_checks.h"

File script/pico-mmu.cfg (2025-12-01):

[gcode_shell_command mmu_cmd]
command: /usr/bin/python3 /usr/data/printer_data/config/pico-mmu/mmu_cmd.py
timeout: 86400.0

[gcode_macro MMU_STATE]
variable_current_filament: 0
variable_first_change: True
gcode:
    M118 MMU_STATE.current_filament = {current_filament}
    M118 MMU_STATE.first_change = {first_change}

[gcode_macro MMU_START]
gcode:
    SET_GCODE_VARIABLE MACRO=MMU_STATE VARIABLE=first_change VALUE=True

[gcode_macro MMU_MIDI_FINISH]
gcode:
    MMU_MIDI SLOT=4

[gcode_macro MMU_MIDI]
gcode:
    {% set slot = params.SLOT|default(-1)|int %}
    RUN_SHELL_COMMAND CMD=mmu_cmd PARAMS="midi {slot}"

[gcode_macro MMU_CUTTER_POSITION]
gcode:
    {% set position = params.POSITION|default(0)|int %}
    RUN_SHELL_COMMAND CMD=mmu_cmd PARAMS="cutter_position {position}"

[gcode_macro MMU_POSITION]
gcode:
    {% set position = params.POSITION|default(0)|int %}
    RUN_SHELL_COMMAND CMD=mmu_cmd PARAMS="mmu_position {position}"

[gcode_macro MMU_ROTATE]
gcode:
    {% set degrees = params.DEGREES|default(0)|int %}
    RUN_SHELL_COMMAND CMD=mmu_cmd PARAMS="mmu_rotate {degrees}"

[gcode_macro MMU_EXTRUDE]
gcode:
    {% set distance = params.DISTANCE|default(0)|int %}
    RUN_SHELL_COMMAND CMD=mmu_cmd PARAMS="extrude {distance}"

[gcode_macro MMU_RETRACT]
gcode:
    {% set distance = params.DISTANCE|default(0)|int %}
    RUN_SHELL_COMMAND CMD=mmu_cmd PARAMS="retract {distance}"

[gcode_macro MMU_FILAMENT]
gcode:
    {% set index = params.INDEX|default(0)|int %}
    RUN_SHELL_COMMAND CMD=mmu_cmd PARAMS="filament {index}"
    
[gcode_macro MMU_FILAMENT_RELEASE]
gcode:
    RUN_SHELL_COMMAND CMD=mmu_cmd PARAMS="filament_release"

[gcode_macro MMU_FILAMENT_REENGAGE]
gcode:
    RUN_SHELL_COMMAND CMD=mmu_cmd PARAMS="filament_reengage"

[gcode_macro MMU_TEST_LEDS]
gcode:
    RUN_SHELL_COMMAND CMD=mmu_cmd PARAMS="test_leds"

[gcode_macro MMU_TEST_LED]
gcode:
    {% set led = params.LED|default(0)|int %}
    RUN_SHELL_COMMAND CMD=mmu_cmd PARAMS="test_led {led}"

[gcode_macro MMU_SWITCH_FILAMENT]
variable_filament_positions: 170,148,126,104,80,56,32,10
variable_first_change_purge_distance: 200
variable_extruder_temperature_min: 190
variable_cut_distance: 30
variable_extrude_distance: 32
variable_extrude_speed: 500
variable_retract_distance: 60
variable_retract_speed: 210
variable_mm_per_rotation: 18.28571429
variable_mm_to_stuck: 80
variable_cutter_position_opened: 0
variable_cutter_position_closed: 120
gcode:
    {% set filament = params.FILAMENT | int %}
    {% set current_filament = printer["gcode_macro MMU_STATE"].current_filament %}
    {% set first_change = printer["gcode_macro MMU_STATE"].first_change in ["True", "true", True] %}
    {% set temp = printer.extruder.temperature %}
    {% set fan_speed = printer["gcode_macro M106"].speed %}

    RUN_SHELL_COMMAND CMD=mmu_cmd PARAMS="sync FILAMENT_POSITIONS {filament_positions} EXTRUDE_MM {extrude_distance} RETRACT_MM {retract_distance} MM_PER_ROTATION {mm_per_rotation} MM_TO_STUCK {mm_to_stuck} CUTTER_OPENED {cutter_position_opened} CUTTER_CLOSED {cutter_position_closed}"

    {% if current_filament == filament %}
        M118 The filament {filament} is already selected

    {% else %}
        SET_GCODE_VARIABLE MACRO=MMU_STATE VARIABLE=current_filament VALUE={filament}

        SAVE_GCODE_STATE NAME=mmu_switch_filament

        M106 S0

        {% if temp < extruder_temperature_min %}
            M118 Waiting for extruder to reach {extruder_temperature_min}°C...
            M109 S{extruder_temperature_min} 
        {% endif %}

        {% if 'x' not in printer.toolhead.homed_axes %}
            M118 Homing required, running G28...
            G28 X
        {% endif %}

        {% if 'z' in printer.toolhead.homed_axes %}
            G91
            G0 Z2 F30000
        {% endif %}

        G90
        G0 X-12 F30000

        M83
        G1 E-{cut_distance} F2000

        M400

        {% if 'z' in printer.toolhead.homed_axes %}
            G91
            G0 Z-2 F30000
        {% endif %}
        
        RUN_SHELL_COMMAND CMD=mmu_cmd PARAMS="cutter_position {cutter_position_closed}"
        RUN_SHELL_COMMAND CMD=mmu_cmd PARAMS="cutter_position {cutter_position_opened}"
        M400

        RUN_SHELL_COMMAND CMD=mmu_cmd PARAMS="filament_reengage"      
        RUN_SHELL_COMMAND CMD=mmu_cmd PARAMS="retract {retract_distance} {retract_speed}"
        G1 E-130 F2000
        M400

        RUN_SHELL_COMMAND CMD=mmu_cmd PARAMS="filament {filament}"
        RUN_SHELL_COMMAND CMD=mmu_cmd PARAMS="extrude {extrude_distance} {extrude_speed}"
        
        G1 E56 F1000
        RUN_SHELL_COMMAND CMD=mmu_cmd PARAMS="filament_release"
        M400
        
        RUN_SHELL_COMMAND CMD=mmu_cmd PARAMS="swap_finish"

        {% if first_change %}
            M106 S255
            G1 E{first_change_purge_distance} F500
        {% endif %}

        G90
        M82
        M106 S{fan_speed} 

        {% if temp < extruder_temperature_min %}
            M104 S{temp}
        {% endif %}

        RESTORE_GCODE_STATE NAME=mmu_switch_filament
    {% endif %}
    
    SET_GCODE_VARIABLE MACRO=MMU_STATE VARIABLE=first_change VALUE=False
    ;test

[gcode_macro T0]
gcode:
    MMU_SWITCH_FILAMENT FILAMENT=0

[gcode_macro T1]
gcode:
    MMU_SWITCH_FILAMENT FILAMENT=1

[gcode_macro T2]
gcode:
    MMU_SWITCH_FILAMENT FILAMENT=2

[gcode_macro T3]
gcode:
    MMU_SWITCH_FILAMENT FILAMENT=3

[gcode_macro T4]
gcode:
    MMU_SWITCH_FILAMENT FILAMENT=4

[gcode_macro T5]
gcode:
    MMU_SWITCH_FILAMENT FILAMENT=5

[gcode_macro T6]
gcode:
    MMU_SWITCH_FILAMENT FILAMENT=6

[gcode_macro T7]
gcode:
    MMU_SWITCH_FILAMENT FILAMENT=7

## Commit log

2025-08-06 PCB files
    [pcb.stl, protoboard-diagram.fzz]
2025-08-06 Performance improvement
    [pico-mmu.cfg]
2025-08-07 Increment stability
    [pico-mmu.cfg]
2025-08-07 Increase logs
    [pico-mmu.cfg]
2025-08-08 Adjust power loss recovery script to work with Orca Slicer Prime Tower
2025-08-11 New HUB config
    [pico-mmu.cfg]
2025-09-23 Update README for Arduino Nano and Ender 3 V3 KE
2025-09-25 Add compile-time checks and fix variable naming inconsistencies in main.cpp
    [main.cpp]
2025-09-26 fix(mmuv2): parse FILAMENT_POSITIONS with explicit parens
    - switch to parsing FILAMENT_POSITIONS using parentheses and comma-separated values
    - decouple runtime PIN output expectations from input parsing logic
    - update config to inject RUN_SHELL_COMMAND for syncing FILAMENT_POSITIONS
    - adjust Arduino alive timeout handling to improve resilience
    [pico-mmu.cfg]
2025-10-03 Add filament hub models and adjust delay in async retraction
    [filament-hub.3mf, filament-hub.stl]
2025-10-09 Enhance button control and cutter position handling in main.cpp and pico-mmu.cfg
    [pico-mmu.cfg]
2025-10-14 docs: rewrite README for Pico MMU, add hardware models, tweak config & cleanup
    - Replace Nano-focused README with a comprehensive "Creality Pico MMU" guide:
    - Expanded features, hardware list, pin mapping, assembly, software architecture, Klipper integration, examples, troubleshooting and development notes
    - Clarified build/flash instructions, supported boards, dependencies and serial protocol
    - Updated license to Apache-2.0 and included third-party attributions
    - Add 3D assets for filament cutter and filament hub:
    - models/filament-cutter/* (STL, 3MF, gears, frames, supports, adapters)
    - models/filament-hub/* (STL, 3MF, cover)
    - Ensure printable files and assembly recommendatio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
    [blade-support.stl, cutter-base.stl, fan-adapter-40mm.stl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]
2025-10-23 fix(mmu): turn off part cooling fan before swap and enable full fan only for first-change purge, optimized for ABS, PETG and another filaments
    [pico-mmu.cfg]
2025-12-01 fix(mmu): adjust first change purge distance to 200 and refine cutter movement parameters
    [pico-mmu.cfg]
2026-03-06 feat(models): add new filament hub and gantry support models; update mmu_daemon.py for improved error handling
    [base.stl, cover.stl, crankshaft-pulley.stl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]
